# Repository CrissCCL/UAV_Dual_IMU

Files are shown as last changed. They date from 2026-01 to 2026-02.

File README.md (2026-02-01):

# 📐🛩️ UAV Dual IMU Evaluation Board







## Overview

This repository documents an **updated inertial sensing stage for an unmanned aerial vehicle (UAV)**, developed as a **standalone PCB** to improve measurement quality, stability, and robustness of inertial measurements.

Originally, the UAV used an **MPU6050 IMU** integrated into the control PCB for inertial measurements.  
In this revision, inertial sensing was **fully separated into a dedicated evaluation board**, enabling **simultaneous measurement and comparison** of two different IMUs:

- **BMI088** (Bosch)
- **ICM-42605** (TDK InvenSense)

This modular architecture supports informed hardware decisions before final integration into the flight control system.

## 📂 Contents

- `/Hardware` → schematic, Gerbers and BOM+POS for PCBA.
- `/test_dual_angle_failover` → C code for Teensy/Arduino.

## 🌐 YouTube

📺 [Failover IMU](https://youtube.com/shorts/ujR3OjFHcZo)

## 🔗 Project Context

This dual IMU evaluation board is part of the ongoing hardware updates for the **DIY UAV project**.

The main project repository documents the overall UAV system, including mechanical design, control architecture, and system integration:

- **DIY UAV – Main Project Repository**  
  [DIY UAV](https://github.com/CrissCCL/DIY_UAV)

This repository focuses exclusively on **inertial sensor evaluation and validation**, separated from the control and power stages to improve system robustness and scalability.

## 🧠 Inertial Sensing Stage Description

The board integrates two IMUs operating simultaneously on the same PCB.

### Integrated Sensors

- **BMI088** (Bosch)
  - Industrial-grade accelerometer and gyroscope
  - High vibration tolerance
  - Designed for harsh motion environments

- **ICM-42605** (TDK InvenSense)
  - High-performance accelerometer and gyroscope
  - Low noise density
  - High bandwidth suitable for dynamic maneuvers

Both sensors are powered, clocked, and sampled under the same conditions, allowing direct and fair comparison.

## 🔗 Measurement Architecture

Both IMUs are integrated on the same PCB and operate simultaneously under identical conditions.

```text
IMU Evaluation Board
  │
  ├── BMI088     ──► Accel + Gyro Data
  │
  └── ICM-42605  ──► Accel + Gyro Data
            │
            └──► MCU / Data Acquisition
```

## 🎯 Evaluation Objectives

The purpose of this board is to:

- Improve **measurement quality and stability**
- Evaluate noise characteristics under identical conditions
- Compare dynamic response of different IMUs
- Enable **simultaneous inertial measurements**
- Support future **sensor fusion and redundancy strategies**

These objectives are critical for robust state estimation in UAV applications.

## 🔄 Measurement Strategy

The evaluation methodology ensures consistency across both sensors:

- Same mechanical mounting
- Same PCB layout and ground reference
- Same power supply domain
- Same sampling rate and acquisition timing
- Same data processing pipeline

This guarantees that observed differences are attributable to **sensor characteristics**, not system-level artifacts.

## ✅ Test Results — IMU Failover (IMU1 → IMU2)

A failover test was performed to validate the system behavior when the primary IMU becomes unavailable or unstable.

### Test Objective
Verify that the system can automatically switch from **IMU1** to **IMU2** during runtime, maintaining valid inertial measurements.

### Test Method
- **IMU1** was configured as the primary sensor at startup.
- A fault condition was introduced on IMU1 (disconnect / communication loss / invalid readings).
- The system monitored the IMU health status and triggered a failover event.
- After failover, **IMU2** was selected as the active sensor.

### Failover Criteria (Health Check)
The system triggers the IMU switch when one of the following conditions is detected:
- I2C timeout / no response
- Out-of-range or invalid sensor values
- Persistent mismatch between IMU1 and IMU2
- Consecutive mismatch counter exceeding a threshold

### 🔁 Dual-IMU Comparison + Automatic Failover Logic (Flowchart)

<p align="center">
  flowchart
</p>

### Results Summary
- ✅ Failover successfully triggered when IMU1 fault condition was detected
- ✅ IMU2 became the active sensor and continued streaming valid data
- ✅ No system reset was required during the switch
- ✅ Recovery behavior confirmed (optional: switch back to IMU1 if restored)

### Evidence (Plots / Logs)

**Example output format (CSV):**
`roll, pitch, yaw, primary, mismatch, cnt`

- `primary = 0` → IMU1 active  
- `primary = 1` → IMU2 active  

<p align="center">
imu_failover_test
</p>

> 📌 **Note:** During the failover event, `primary` changes from **0 → 1**, confirming the sensor switch.

## 🖼️ PCB Render Visualization

<table>
  <tr>
    <td align="center">
      dual IMU_module top V2<br>
      <sub> Dual IMU PCB V2 – Top View </sub>
    </td>
    <td align="center">
        dual IMU_module botton V2<br>
      <sub> Dual IMU PCB V2 – Bottom View </sub>
    </td>
  </tr>
</table>

## ⚡ Physical Prototype

The following image shows the complete setup of the **prototype version V1**:

<table>
  <tr>
    <td align="center">
      dual IMU_module PCB<br>
      <sub> Dual IMU PCB unmounted </sub>
    </td>
    <td align="center">
        dual IMU_module PCB V1<br>
      <sub> Dual IMU PCB </sub>
    </td>
  </tr>
</table>

## ⚠️ Disclaimer

This project is intended **for educational and experimental purposes only**.  
It is not a flight-certified inertial sensing module.

## 🤝 Support projects
 Support me on Patreon [https://www.patreon.com/c/CrissCCL](https://www.patreon.com/c/CrissCCL)

## 📜 License
MIT License

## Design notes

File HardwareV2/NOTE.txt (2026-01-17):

If you are going to manufacture the PCB using PCBA, or if you are going to purchase the components separately, replace Capacitor_SMD:CP_Elec_4x4.5 with:

-40°C to +85°C 2.2µF 2000hrs@85°C 4mm 5.5mA@100kHz 50V 5mm ±20% SMD, D4xL5mm Aluminum Electrolytic Capacitors - SMD ROHS

Note: The closest commercially available capacitor size is 4x5mm.

If you are going to manufacture the PCB using PCBA, review and adjust any components that show warnings to match the available parts list on the website.

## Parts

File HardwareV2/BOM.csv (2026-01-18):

Reference | Qty | Value | DNP | Exclude from BOM | Exclude from Board | Footprint | Datasheet
AC1 | 1 | ICM-42605 |  |  |  | SamacSys_Parts:IIM42352 | https://3cfeqx1hf82y3xcoull08ihx-wpengine.netdna-ssl.com/wp-content/uploads/2020/09/DS-000292-ICM-42605-v1.5.pdf
C1,C2,C4 | 3 | 100n |  |  |  | Capacitor_SMD:C_1206_3216Metric_Pad1.33x1.80mm_HandSolder | ~
C3 | 1 | 10n |  |  |  | Capacitor_SMD:C_1206_3216Metric_Pad1.33x1.80mm_HandSolder | ~
C6 | 1 | 2.2u |  |  |  | Capacitor_SMD:CP_Elec_4x4.5 | ~
J2 | 1 | Conn_01x06_Pin |  |  |  | Connector_PinHeader_2.54mm:PinHeader_1x06_P2.54mm_Vertical | ~
R1,R2,R3,R4 | 4 | 4.7k |  |  |  | Resistor_SMD:R_1206_3216Metric_Pad1.30x1.75mm_HandSolder | ~
U1 | 1 | BMI088 |  |  |  | Package_LGA:Bosch_LGA-16_4.5x3mm_P0.5mm_LayoutBorder7x1y_ClockwisePinNumbering | https://www.bosch-sensortec.com/media/boschsensortec/downloads/datasheets/bst-bmi088-ds001.pdf

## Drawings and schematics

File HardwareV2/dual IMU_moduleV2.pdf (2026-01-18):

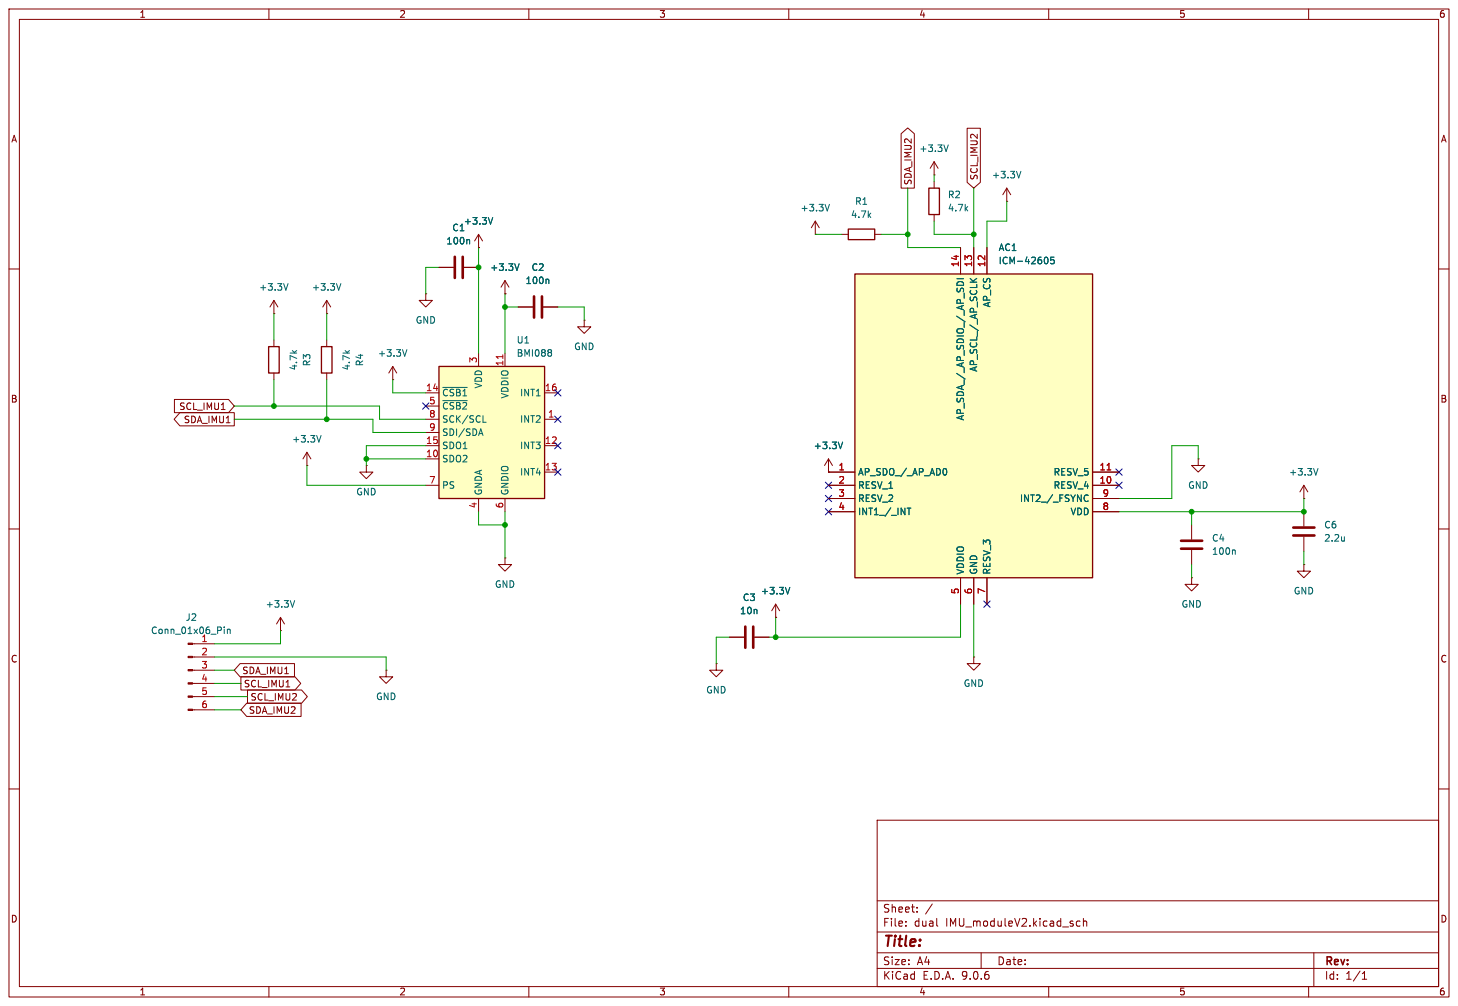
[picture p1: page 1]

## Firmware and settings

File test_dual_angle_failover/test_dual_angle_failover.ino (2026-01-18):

#include <Arduino.h>
#include <Wire.h>

// =====================
// IMU selection (auto failover)
// =====================
enum ImuSelect { IMU_PRIMARY_BMI, IMU_PRIMARY_ICM };
static ImuSelect PRIMARY_IMU = IMU_PRIMARY_BMI;   // arranque

// =====================
// Direcciones I2C
// =====================
static const uint8_t BMI_ACC_ADDR = 0x18;
static const uint8_t BMI_GYR_ADDR = 0x68;
static const uint8_t ICM_ADDR     = 0x69;

// I2C clocks
static const uint32_t I2C0_FREQ = 400000; // Wire  (BMI)
static const uint32_t I2C1_FREQ = 100000; // Wire1 (ICM robust)

// =====================
// Estado
// =====================
bool bmi_ok=false, icm_ok=false;
bool bmi_data_ok=false, icm_data_ok=false;

// Raw->units por IMU
float bmi_ax=0,bmi_ay=0,bmi_az=0, bmi_gx=0,bmi_gy=0,bmi_gz=0; // g, deg/s
float icm_ax=0,icm_ay=0,icm_az=0, icm_gx=0,icm_gy=0,icm_gz=0; // g, deg/s

// Primary outputs (para tu controlador después)
float AccX=0,AccY=0,AccZ=0;
float RateRoll=0,RatePitch=0,RateYaw=0;

// =====================
// Helpers
// =====================
static inline int16_t le16(uint8_t lsb, uint8_t msb) { return (int16_t)((msb << 8) | lsb); }
static inline int16_t be16(uint8_t msb, uint8_t lsb) { return (int16_t)((msb << 8) | lsb); }
static inline float   rad2deg(float r){ return r * 57.2957795f; }

// =====================
// BMI088 regs
// =====================
static const uint8_t BMI_ACC_DATA_X_L  = 0x12;
static const uint8_t BMI_ACC_RANGE     = 0x41;
static const uint8_t BMI_ACC_PWR_CONF  = 0x7C;
static const uint8_t BMI_ACC_PWR_CTRL  = 0x7D;
static const uint8_t BMI_ACC_SOFTRESET = 0x7E;

static const uint8_t BMI_GYR_RATE_X_L  = 0x02;
static const uint8_t BMI_GYR_RANGE     = 0x0F;
static const uint8_t BMI_GYR_BANDWIDTH = 0x10;
static const uint8_t BMI_GYR_LPM1      = 0x11;
static const uint8_t BMI_GYR_SOFTRESET = 0x14;

// =====================
// ICM-42605 regs (Bank0)
// =====================
static const uint8_t ICM_BANK_SEL       = 0x76;
static const uint8_t ICM_DEVICE_CONFIG  = 0x11;
static const uint8_t ICM_WHO_AM_I       = 0x75; // 0x42
static const uint8_t ICM_INTF_CONFIG1   = 0x4D;
static const uint8_t ICM_PWR_MGMT0      = 0x4E;
static const uint8_t ICM_GYRO_CONFIG0   = 0x4F;
static const uint8_t ICM_ACCEL_CONFIG0  = 0x50;
static const uint8_t ICM_ACCEL_DATA_X1  = 0x1F;
static const uint8_t ICM_GYRO_DATA_X1   = 0x25;

// =====================
// Wire (BMI) helpers
// =====================
static bool w_write8(uint8_t addr, uint8_t reg, uint8_t val) {
  Wire.beginTransmission(addr);
  Wire.write(reg); Wire.write(val);
  return (Wire.endTransmission(true) == 0);
}
static bool w_readN(uint8_t addr, uint8_t startReg, uint8_t *buf, size_t n) {
  Wire.beginTransmission(addr);
  Wire.write(startReg);
  if (Wire.endTransmission(false) != 0) return false;
  size_t got = Wire.requestFrom((int)addr, (int)n);
  if (got != n) return false;
  for (size_t i=0;i<n;i++) buf[i]=Wire.read();
  return true;
}

// =====================
// Wire1 (ICM) robust helpers
// =====================
static bool w1_write8_stop(uint8_t addr, uint8_t reg, uint8_t val) {
  Wire1.beginTransmission(addr);
  Wire1.write(reg); Wire1.write(val);
  return (Wire1.endTransmission(true) == 0);
}
static bool w1_read8_stop(uint8_t addr, uint8_t reg, uint8_t &val) {
  Wire1.beginTransmission(addr);
  Wire1.write(reg);
  if (Wire1.endTransmission(true) != 0) return false;
  delayMicroseconds(80);
  if (Wire1.requestFrom((int)addr, 1) != 1) return false;
  val = Wire1.read();
  return true;
}
static bool w1_read6_bytewise(uint8_t addr, uint8_t startReg, uint8_t out6[6]) {
  for (int i=0;i<6;i++) {
    if (!w1_read8_stop(addr, startReg + i, out6[i])) return false;
  }
  return true;
}

// =====================
// BMI init + read
// =====================
static bool bmi_init() {
  if (!w_write8(BMI_ACC_ADDR, BMI_ACC_SOFTRESET, 0xB6)) return false;
  delay(2);
  if (!w_write8(BMI_ACC_ADDR, BMI_ACC_PWR_CONF, 0x00)) return false;
  delay(1);
  if (!w_write8(BMI_ACC_ADDR, BMI_ACC_PWR_CTRL, 0x04)) return false;
  delay(5);
  if (!w_write8(BMI_ACC_ADDR, BMI_ACC_RANGE, 0x01)) return false; // +/-6g

  if (!w_write8(BMI_GYR_ADDR, BMI_GYR_SOFTRESET, 0xB6)) return false;
  delay(35);
  if (!w_write8(BMI_GYR_ADDR, BMI_GYR_LPM1, 0x00)) return false;
  delay(1);
  if (!w_write8(BMI_GYR_ADDR, BMI_GYR_RANGE, 0x00)) return false; // +/-2000 dps
  if (!w_write8(BMI_GYR_ADDR, BMI_GYR_BANDWIDTH, 0x02)) return false;

  return true;
}

static bool bmi_read_units(float &ax_g, float &ay_g, float &az_g,
                           float &gx_dps, float &gy_dps, float &gz_dps) {
  uint8_t a[6], g[6];
  if (!w_readN(BMI_ACC_ADDR, BMI_ACC_DATA_X_L, a, 6)) return false;
  if (!w_readN(BMI_GYR_ADDR, BMI_GYR_RATE_X_L, g, 6)) return false;

  int16_t ax = le16(a[0],a[1]);
  int16_t ay = le16(a[2],a[3]);
  int16_t az = le16(a[4],a[5]);

  int16_t gx = le16(g[0],g[1]);
  int16_t gy = le16(g[2],g[3]);
  int16_t gz = le16(g[4],g[5]);

  const float ACC_LSB_PER_G   = 5460.0f;
  const float GYR_LSB_PER_DPS = 16.4f;

  ax_g = (float)ax / ACC_LSB_PER_G;
  ay_g = (float)ay / ACC_LSB_PER_G;
  az_g = (float)az / ACC_LSB_PER_G;

  gx_dps = (float)gx / GYR_LSB_PER_DPS;
  gy_dps = (float)gy / GYR_LSB_PER_DPS;
  gz_dps = (float)gz / GYR_LSB_PER_DPS;

  return true;
}

// =====================
// ICM init + read
// =====================
static bool icm_init_strict() {
  if (!w1_write8_stop(ICM_ADDR, ICM_BANK_SEL, 0x00)) return false;
  delay(1);

  if (!w1_write8_stop(ICM_ADDR, ICM_DEVICE_CONFIG, 0x01)) return false; // reset
  delay(3);

  if (!w1_write8_stop(ICM_ADDR, ICM_BANK_SEL, 0x00)) return false;
  delay(1);

  uint8_t who=0;
  if (!w1_read8_stop(ICM_ADDR, ICM_WHO_AM_I, who)) return false;
  if (who != 0x42) return false;

  (void)w1_write8_stop(ICM_ADDR, ICM_INTF_CONFIG1, 0x01); // disable I3C
  delay(1);

  if (!w1_write8_stop(ICM_ADDR, ICM_GYRO_CONFIG0,  0x06)) return false;
  if (!w1_write8_stop(ICM_ADDR, ICM_ACCEL_CONFIG0, 0x06)) return false;

  if (!w1_write8_stop(ICM_ADDR, ICM_PWR_MGMT0, 0x0F)) return false; // accel+gyro LN
  delay(70);

  return true;
}

static bool icm_read_units(float &ax_g, float &ay_g, float &az_g,
                           float &gx_dps, float &gy_dps, float &gz_dps) {
  (void)w1_write8_stop(ICM_ADDR, ICM_BANK_SEL, 0x00);
  delayMicroseconds(80);

  uint8_t pm=0;
  if (w1_read8_stop(ICM_ADDR, ICM_PWR_MGMT0, pm)) {
    if (pm != 0x0F) {
      (void)w1_write8_stop(ICM_ADDR, ICM_PWR_MGMT0, 0x0F);
      delay(70);
    }
  }

  uint8_t a[6], g[6];
  if (!w1_read6_bytewise(ICM_ADDR, ICM_ACCEL_DATA_X1, a)) return false;
  if (!w1_read6_bytewise(ICM_ADDR, ICM_GYRO_DATA_X1,  g)) return false;

  int16_t ax = be16(a[0],a[1]);
  int16_t ay = be16(a[2],a[3]);
  int16_t az = be16(a[4],a[5]);

  int16_t gx = be16(g[0],g[1]);
  int16_t gy = be16(g[2],g[3]);
  int16_t gz = be16(g[4],g[5]);

  const float ACC_LSB_PER_G   = 2048.0f;
  const float GYR_LSB_PER_DPS = 16.4f;

  ax_g = (float)ax / ACC_LSB_PER_G;
  ay_g = (float)ay / ACC_LSB_PER_G;
  az_g = (float)az / ACC_LSB_PER_G;

  gx_dps = (float)gx / GYR_LSB_PER_DPS;
  gy_dps = (float)gy / GYR_LSB_PER_DPS;
  gz_dps = (float)gz / GYR_LSB_PER_DPS;

  return true;
}

// =====================
// Init + update
// =====================
static void imu_init() {
  Wire.begin();
  Wire.setClock(I2C0_FREQ);

  Wire1.setSDA(17);
  Wire1.setSCL(16);
  Wire1.begin();
  Wire1.setClock(I2C1_FREQ);

  bmi_ok = bmi_init();
  icm_ok = icm_init_strict();
}

static void set_primary(ImuSelect sel) {
  PRIMARY_IMU = sel;
}

static void imu_update() {
  bmi_data_ok = bmi_read_units(bmi_ax,bmi_ay,bmi_az, bmi_gx,bmi_gy,bmi_gz);
  icm_data_ok = icm_read_units(icm_ax,icm_ay,icm_az, icm_gx,icm_gy,icm_gz);

  if (PRIMARY_IMU == IMU_PRIMARY_BMI) {
    AccX=bmi_ax; AccY=bmi_ay; AccZ=bmi_az;
    RateRoll=bmi_gx; RatePitch=bmi_gy; RateYaw=bmi_gz;
  } else {
    AccX=icm_ax; AccY=icm_ay; AccZ=icm_az;
    RateRoll=icm_gx; RatePitch=icm_gy; RateYaw=icm_gz;
  }
}

// =====================
// Angles (complementary per IMU)
// =====================
static float bmi_roll=0, bmi_pitch=0;
static float icm_roll=0, icm_pitch=0;
static uint32_t t_prev=0;

// =====================
// Mismatch + failover config
// =====================
static const float MISMATCH_DEG   = 5.0f;   // umbral grados
static const int   MISMATCH_HITS  = 10;     // ciclos seguidos
static const uint32_t FAILOVER_COOLDOWN_MS = 1500; // no cambiar de nuevo por X ms

static int mismatch_counter = 0;
static bool imu_mismatch = false;
static uint32_t last_failover_ms = 0;

static void mismatch_update(float dRoll, float dPitch) {
  // mismatch logic: solo si ambas están OK
  if (bmi_data_ok && icm_data_ok) {
    if (fabsf(dRoll) > MISMATCH_DEG || fabsf(dPitch) > MISMATCH_DEG) mismatch_counter++;
    else mismatch_counter--;
  } else {
    mismatch_counter++; // si una cae, cuenta mismatch
  }

  if (mismatch_counter < 0) mismatch_counter = 0;
  if (mismatch_counter > MISMATCH_HITS) mismatch_counter = MISMATCH_HITS;

  imu_mismatch = (mismatch_counter >= MISMATCH_HITS);
}

static void maybe_failover() {
  if (!imu_mismatch) return;

  uint32_t now = millis();
  if (now - last_failover_ms < FAILOVER_COOLDOWN_MS) return;

  // Si la primaria es BMI y ICM está OK -> cambia a ICM
  if (PRIMARY_IMU == IMU_PRIMARY_BMI) {
    if (icm_data_ok) {
      set_primary(IMU_PRIMARY_ICM);
      last_failover_ms = now;
      mismatch_counter = 0; // resetea para evitar rebote inmediato
      Serial.println(">>> FAILOVER: PRIMARY -> ICM42605");
    }
  } else {
    // primaria es ICM, si BMI está OK -> cambia a BMI
    if (bmi_data_ok) {
      set_primary(IMU_PRIMARY_BMI);
      last_failover_ms = now;
      mismatch_counter = 0;
      Serial.println(">>> FAILOVER: PRIMARY -> BMI088");
    }
  }
}

void setup() {
  Serial.begin(115200);
  delay(200);

  imu_init();

  Serial.println("Teensy 4.0 - Dual IMU compare + mismatch + auto failover");
  Serial.print("START PRIMARY_IMU = "); Serial.println(PRIMARY_IMU == IMU_PRIMARY_BMI ? "BMI088" : "ICM42605");
  Serial.print("BMI init: "); Serial.println(bmi_ok ? "OK" : "FAIL");
  Serial.print("ICM init: "); Serial.println(icm_ok ? "OK" : "FAIL");

  t_prev = micros();
}

void loop() {
  // dt real
  uint32_t t_now = micros();
  float dt = (t_now - t_prev) * 1e-6f;
  if (dt <= 0) dt = 0.005f;
  if (dt > 0.05f) dt = 0.005f;
  t_prev = t_now;

  imu_update();

  // Angulos ACC
  float bmi_roll_acc  = rad2deg(atan2f(bmi_ay, sqrtf(bmi_ax*bmi_ax + bmi_az*bmi_az)));
  float bmi_pitch_acc = -rad2deg(atan2f(bmi_ax, sqrtf(bmi_ay*bmi_ay + bmi_az*bmi_az)));

  float icm_roll_acc  = rad2deg(atan2f(icm_ay, sqrtf(icm_ax*icm_ax + icm_az*icm_az)));
  float icm_pitch_acc = -rad2deg(atan2f(icm_ax, sqrtf(icm_ay*icm_ay + icm_az*icm_az)));

  // Complementary
  const float alpha = 0.98f;

  if (bmi_data_ok) {
    bmi_roll  = alpha*(bmi_roll  + bmi_gx*dt) + (1.0f-alpha)*bmi_roll_acc;
    bmi_pitch = alpha*(bmi_pitch + bmi_gy*dt) + (1.0f-alpha)*bmi_pitch_acc;
  }
  if (icm_data_ok) {
    icm_roll  = alpha*(icm_roll  + icm_gx*dt) + (1.0f-alpha)*icm_roll_acc;
    icm_pitch = alpha*(icm_pitch + icm_gy*dt) + (1.0f-alpha)*icm_pitch_acc;
  }

  // Delta + mismatch + failover
  float dRoll  = bmi_roll  - icm_roll;
  float dPitch = bmi_pitch - icm_pitch;

  mismatch_update(dRoll, dPitch);
  maybe_failover();

  // Print ~100 Hz
  static uint32_t t_print=0;
  if (millis() - t_print >= 10) {
    t_print = millis();

    Serial.print("P=");
    Serial.print(PRIMARY_IMU == IMU_PRIMARY_BMI ? "BMI" : "ICM");
    Serial.print("  ");

    Serial.print("BMI("); Serial.print(bmi_data_ok); Serial.print(") ");
    Serial.print("r,p="); Serial.print(bmi_roll,1); Serial.print(",");
    Serial.print(bmi_pitch,1);

    Serial.print("  ||  ");

    Serial.print("ICM("); Serial.print(icm_data_ok); Serial.print(") ");
    Serial.print("r,p="); Serial.print(icm_roll,1); Serial.print(",");
    Serial.print(icm_pitch,1);

    Serial.print("  ||  ");
    Serial.print("d="); Serial.print(dRoll,1); Serial.print(",");
    Serial.print(dPitch,1);

    Serial.print("  ||  ");
    Serial.print("MISMATCH="); Serial.print(imu_mismatch ? "YES" : "NO");
    Serial.print(" (cnt="); Serial.print(mismatch_counter); Serial.print(")");

    Serial.println();
  }
}
